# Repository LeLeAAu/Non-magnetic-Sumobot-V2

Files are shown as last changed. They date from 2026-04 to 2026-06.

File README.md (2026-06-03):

# English
# Non-magnetic-Sumobot-V2

## I. Overview
An autonomous ESP32-based robot specifically designed for the UTC SumoBot competition. The project focuses on asymmetric mechanical design and multithreaded processing (FreeRTOS) to optimize high-speed tactical reaction performance.

* **Status:** In Development.
* **License:** MIT License.

Render

---

## II. Directory Structure
* `/main`: Main source code and firmware.
* `/debug`: Testing and sensor calibration code.
* `/Documents`: Research documents, opponent meta analysis, and circuit schematics.
* `/Images`: Project diagrams and images.

---

## III. UTC Competition Rules
* **Dimensions:** Maximum 15x15cm, unlimited height.
* **Weight:** Maximum 1.5kg.
* **Arena (Dohyo):** Circular arena with a 100cm diameter and a 5cm white border. The surface is non-metallic, and magnets are prohibited.
* **Operation:** Fully autonomous. A mandatory 3-second delay before movement must be programmed.
* **Match Format:** 3 rounds, 3 minutes per round. Victory is achieved by flipping or pushing the opponent out of the arena. If both robots fall simultaneously, the robot that touches the ground last wins.

---

## IV. Mechanical & Weight Strategy
The total estimated hardware weight is approximately **1256g**. Instead of maximizing ballast to reach the 1.5kg limit, the bot adopts a "Lightweight & Agile" strategy:

1. **High Mobility:** Reduced inertia allows rapid acceleration and fast flanking maneuvers, exploiting the sluggish movement characteristics commonly found in Tanker-type bots.

2. **Opponent Counterplay:** Most opponents tend to expose their sides and rear. Despite the lower weight, the use of self-locking Worm Gear motors prevents the bot from being pushed backward. This is combined with a Teflon-coated wedge that stays close to the arena floor to lift the opponent's center of mass.

---

## V. Hardware Architecture
* **ESP32 Dual-Core (240MHz):** Processing tasks separated using FreeRTOS.
* **ToF Sensor Array (5x VL53L1X):** Provides 360-degree coverage. Independent XSHUT pins are used for sequential I2C address assignment during startup.
* **Infrared Sensors (5x TCRT5000):** Four edge-detection sensors for white border detection, plus one upward-facing underbody sensor to confirm when the opponent has been lifted onto the wedge.
* **IMU (LSM6DS3):** 6-axis accelerometer and gyroscope sensor. Detects impacts (G-force) and activates the Anti-Lift mechanism.
* **Power System:** High-discharge LiPo 3S 1500mAh 45C battery, Mini560PRO compact buck converter dedicated to the microcontroller power supply, and BTS7960 high-power motor drivers.

---

## VI. Software Architecture & FSM
The system operates using a non-blocking multithreaded architecture:

* **Core 0 (TaskSensor):** Continuously scans the I2C bus. Applies a Median filter for distance measurements and an EMA filter to estimate enemy approach velocity ($v_e$).

* **Core 1 (TaskFSM):** Controls the Finite State Machine (FSM) and PWM signal generation. Data shared between both cores is synchronized safely using a Spinlock Mutex.

---

## VII. ESP32 Pinout
* **Edge & Underbody Sensors (TCRT5000):**
    * Underbody Sensor (DETECT) -> Pin 18 (GPIO39).
    * Rear Left -> Pin 19 (GPIO34). Rear Right -> Pin 20 (GPIO35).
    * Front Left -> Pin 21 (GPIO32). Front Right -> Pin 22 (GPIO33).

* **Main I2C Bus:**
    * SCL -> Pin 23 (GPIO25).
    * SDA -> Pin 24 (GPIO26).

* **XSHUT Control (VL53L1X):**
    * Center (GPIO27), Left (GPIO14), Right (GPIO13), Left Side (GPIO16), Right Side (GPIO17).

* **Motor Driver (BTS7960):**
    * Right LPWM (GPIO18), Right RPWM (GPIO19), Left LPWM (GPIO21), Left RPWM (GPIO22).

* **UI Interface & Notes:**
    * Touch Start Button (TTP223) -> Pin 5 (GPIO4).
    * I2C OLED -> SDA (GPIO23), SCL (GPIO5).
    * **IMPORTANT WARNING:** Never connect components to Pin 27 (GPIO12), as it may cause boot failure issues. Avoid using RX0 and TX0 pins.
      
# Vietnamese
# Non-magnetic-Sumobot-V2
## I. Tổng quan
Robot tự hành ESP32 thiết kế riêng cho giải SumoBot trường UTC. Dự án tập trung vào thiết kế cơ khí bất đối xứng và xử lý đa luồng (FreeRTOS) để tối ưu phản xạ chiến thuật tốc độ cao.

* **Trạng thái:** Đang phát triển.
* **Giấy phép:** MIT License.
Render
---

## II. Cấu trúc thư mục
* `/main`: Mã nguồn và Firmware chính.
* `/debug`: Code test và hiệu chuẩn cảm biến.
* `/Documents`: Tài liệu nghiên cứu, phân tích meta đối thủ, sơ đồ mạch.
* `/Images`: Sơ đồ và hình ảnh dự án.

---

## III. Luật thi đấu UTC
* **Kích thước:** Tối đa 15x15cm, không giới hạn chiều cao.
* **Trọng lượng:** Tối đa 1.5kg.
* **Sàn đấu (Dohyo):** Tròn, đường kính 100cm, viền trắng 5cm. Sàn không kim loại, cấm sử dụng nam châm.
* **Vận hành:** Tự động 100%. Bắt buộc lập trình chờ 3 giây trước khi di chuyển.
* **Thể thức:** 3 hiệp, 3 phút/hiệp. Thắng khi đẩy lật/rớt đối thủ. Chạm đất sau sẽ thắng nếu cùng rớt.

---

## IV. Chiến lược Cơ khí & Trọng lượng
Tổng trọng lượng linh kiện kỹ thuật khoảng **1256g**. Thay vì cố nhồi nhét tạ cho đủ mốc 1.5kg, bot áp dụng chiến thuật "Nhẹ & Linh hoạt":
1.  **Linh hoạt cao:** Giảm quán tính để dễ dàng bứt tốc và xoay góc tạt sườn, tận dụng nhược điểm lù đù của các bot hệ Tanker.
2.  **Khắc chế đối thủ:** Đa số đối thủ thường hở sườn ngang và lưng. Dù nhẹ cân, nhưng việc sử dụng động cơ Worm Gear tự khóa cơ khí giúp bot không bị đẩy lùi. Kết hợp với lưỡi ủi bọc Teflon ép sát mặt sàn để hất bổng trọng tâm đối phương.

---

## V. Kiến trúc Phần cứng
* **ESP32 Dual-Core (240MHz):** Tách biệt xử lý bằng FreeRTOS.
* **Mắt thần ToF (5x VL53L1X):** Phủ sóng 360 độ. Sử dụng các chân XSHUT độc lập để gán địa chỉ I2C tuần tự khi khởi động.
* **Hồng ngoại (5x TCRT5000):** 4 cảm biến góc dò vạch trắng, 1 cảm biến gầm hướng lên trên để xác nhận khi đối thủ đã bị nạy lên lưỡi ủi.
* **IMU (LSM6DS3):** Cảm biến gia tốc 6 trục. Phát hiện va chạm (G-force) và kích hoạt cơ chế chống nhấc bổng (Anti-Lift).
* **Năng lượng:** Nguồn xả cao từ Pin LiPo 3S 1500mAh 45C, mạch giảm áp Mini560PRO siêu nhỏ cấp nguồn riêng cho vi điều khiển, và driver công suất BTS7960.

---

## VI. Kiến trúc Phần mềm & FSM
Hệ thống chạy đa luồng không tắc nghẽn (Non-blocking):
* **Core 0 (TaskSensor):** Quét I2C liên tục. Áp dụng bộ lọc Median cho dữ liệu khoảng cách và bộ lọc EMA để tính vận tốc tiếp cận của địch ($v_e$).
* **Core 1 (TaskFSM):** Điều khiển Cỗ máy trạng thái hữu hạn (FSM) và băm xung PWM. Dữ liệu giữa hai Core được khóa an toàn bằng Spinlock Mutex.
---

## VII. Sơ đồ chân ESP32 (Pinout)
* **Cảm biến gầm & mép (TCRT5000):**
    * Mắt gầm (DETECT) -> Chân 18 (GPIO39).
    * Trái sau -> Chân 19 (GPIO34). Phải sau -> Chân 20 (GPIO35).
    * Trái trước -> Chân 21 (GPIO32). Phải trước -> Chân 22 (GPIO33).

* **Bus I2C chính:**
    * SCL -> Chân 23 (GPIO25).
    * SDA -> Chân 24 (GPIO26).

* **Điều khiển XSHUT (VL53L1X):**
    * Giữa (GPIO27), Trái (GPIO14), Phải (GPIO13), Sườn trái (GPIO16), Sườn phải (GPIO17).

* **Cầu H (BTS7960):**
    * LPWM Phải (GPIO18), RPWM Phải (GPIO19), LPWM Trái (GPIO21), RPWM Trái (GPIO22).

* **Giao diện UI & Lưu ý:**
    * Nút cảm ứng khởi động (TTP223) -> Chân 5 (GPIO4).
    * I2C OLED -> SDA (GPIO23), SCL (GPIO5).
    * **CẢNH BÁO QUAN TRỌNG:** Tuyệt đối không cắm linh kiện vào chân 27 (GPIO12) để tránh lỗi Boot, bỏ qua chân RX0, TX0.

Sơ đồ nối dây tổng thể và các đi-ốt bảo vệ mạch đều được cung cấp cụ thể dưới dạng file thiết kế đồ họa trong thư mục /Documents (Fritzing).

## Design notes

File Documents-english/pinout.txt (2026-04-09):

Pin 18 (GPIO39/SVN) → Bottom sensor (DETECT)
Pin 19 (GPIO34) → Rear left sensor (BL)
Pin 20 (GPIO35) → Rear right sensor (BR)
Pin 21 (GPIO32) → Front left sensor (FL)
Pin 22 (GPIO33) → Front right sensor (FR)

Pin 23 (GPIO25) → I2C SCL for 5 VLX + LMS
Pin 24 (GPIO26) → I2C SDA for 5 VLX + LMS
(Keep the two I2C wires close together)

Pin 25 (GPIO27) → XSHUT 0 (Center)
Pin 26 (GPIO14) → XSHUT 1 (Left)
Pin 27 (GPIO12) → IGNORE! DO NOT CONNECT ANYTHING HERE!
Pin 28 (GPIO13) → XSHUT 2 (Right)

Pin 5 (GPIO4) → Push button (TTP223)

Pin 6 (GPIO16/RX2) → XSHUT 3 (Left side)
Pin 7 (GPIO17/TX2) → XSHUT 4 (Right side)
(Keep the remaining two XSHUT wires close together)

Pin 9 (GPIO18) → Right LPWM
Pin 10 (GPIO19) → Right RPWM
Pin 11 (GPIO21) → Left LPWM

Pins 12 & 13 (RX0, TX0) → IGNORE! (Reserved for code upload/USB)

Pin 14 (GPIO22) → Left RPWM
Pin 15 (GPIO23) → SDA of 0.96 OLED
Pin 8 (GPIO5) → SCL of 0.96 OLED

LMS CS pin → Connect to 3.3V  
LMS SA0 pin → Connect to 3.3V

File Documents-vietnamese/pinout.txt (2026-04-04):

    Pin 18 (GPIO39/SVN) -> Mắt gầm (DETECT)
    Pin 19 (GPIO34) -> Mắt Trái sau (BL)
    Pin 20 (GPIO35) -> Mắt Phải sau (BR)
    Pin 21 (GPIO32) -> Mắt Trái trước (FL)
    Pin 22 (GPIO33) -> Mắt Phải trước (FR)

    Pin 23 (GPIO25) -> I2C SCL của 5 VLX + LMS
    Pin 24 (GPIO26) -> I2C SDA của 5 VLX + LMS
    (Gom 2 dây I2C sát nhau)

    Pin 25 (GPIO27) -> XSHUT 0 (Giữa)
    Pin 26 (GPIO14) -> XSHUT 1 (Trái)
    Pin 27 (GPIO12) -> BỎ QUA! KHÔNG CẮM GÌ VÀO ĐÂY!
    Pin 28 (GPIO13) -> XSHUT 2 (Phải)

    Pin 5 (GPIO4) -> Nút bấm (TTP223)

    Pin 6 (GPIO16/RX2) -> XSHUT 3 (Sườn Trái)
    Pin 7 (GPIO17/TX2) -> XSHUT 4 (Sườn Phải)
    (Gom 2 dây XSHUT còn lại vào sát nhau)

    Pin 9 (GPIO18) -> LPWM Phải
    Pin 10 (GPIO19) -> RPWM Phải
    Pin 11 (GPIO21) -> LPWM Trái

    Pin 12 & 13 (RX0, TX0) -> BỎ QUA! (Dành cho nạp code/USB).

    Pin 14 (GPIO22) -> RPWM Trái
    Pin 15 (GPIO23) -> SDA của 0.96 LED
	Pin 8 (GPIO5) -> SCL của 0.95 LED
	
	Chân CS của LMS -> Nối lên 3.3V
	Chân SA0 của LMS -> nối lên 3.3V

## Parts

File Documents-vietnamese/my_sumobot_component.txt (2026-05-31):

-> Lưỡi ủi phải đến mức cạo mặt sàn, phải mài thật sắc, ép sát sàn (dùng băng dính Teflon) để đảm bảo 100% khi cụng đầu, xe mình chui xuống xe nó
-> Rửa lốp bằng cồn hoặc nước lau kính trước mỗi trận đấu để tẩy bụi

5x VL53L1X
	25x15.6mm
	2g each
	nối chung SDA và SCL của tất cả 5 cảm biến vào 2 dây duy nhất -> 2 chân 2IC
	5 chân GPIO điều khiển XSHUT riêng biệt

5x TCRT5000
	10.2 x 5.8 x 7mm
	~7 g each
	
shangyi 1500mAh 45C 3S
	 22mm x 35mm x 73mm
	 150g
	
2x 5840-31zy Worm Gear
	115x54x34mm
	355g each
	
2x BTS7960
	40x50x12mm
	20g each
	dùng dây cắm nối chập R_EN và L_EN lại với nhau, rồi nối thẳng lên nguồn 3.3V (hoặc 5V logic)
	
DOIT ESP32 CH340 30P  (VIN, 2x GND, 3V3, EN, VP, VM, TX0, RX0, RX2, TX2, D2, D4, D5, D18, D19, D21, D22, D23, D12->15, D12, D13, D14, D25, D26, D27, D32->D35)
mini560 PRO - 3.3V and mini560 PRO - 5V
	29x18x5.4mm
	6g
	
Gy-lsm6ds3  
	13x18
	2g
	0x6B

TTP223
	24x24
	
0.96LED

tụ 470uF/25V
	// đường kính x cao
	10x12.5mm
	1.5g
	
tụ 0.1uF
	3.2x1.6
	0.1g
	
tụ 1000uF
	10x20mm
	2g
	
Điện trở
	
Công tắc bập bênh KCD1
	21x15 (mặt ngoài) - 19x13 (lỗ cắt lắp đặt)
	3g
	
Bánh xe robot V2 65m bằng cao su Đường kính: 65mm. Bề rộng: 27mm Khớp lục giác: 12mm

// Nối 2 tụ 0.22uF ở mỗi đầu chân âm dương mỗi động cơ ra vỏ kim loại - vỏ kim loại sẽ đóng vai trò như lồng faraday

Khung PETG ~ 230g
VL53L1X tổng 10g
TCRT5000 tổng 2.5g
shangyi 150g
5840-31zy Worm Gear 710g
BTS7960 tổng 40g
DOIT ESP32 CH340 30P 12g
mini560 PRO tổng 12g
Gy-lsm6ds3 2g
TTP223 xanh lớn cho là 5g
Bánh xe robot V2 65mm cho là 60g
Công tắc bập bênh KCD1 cho là 3g
Các tụ điện điện trở cho là 20g
Dây dợ không rõ.

No-load
	Rated Voltage: 12V
	RPM 260
	Current 0.3A
Rated-load
	RPM 200
	Current 1.6A
	Torque 5kg.cm
	Power 19.2W
Stall
	Torque 25kg.cm
	Current 6.5A
Starting voltage 2V

Input Voltage: 6 ~ 27Vdc.
Driver: Dual BTS7960 H Bridge Configuration.
Peak current: 43-Amp.
PWM capability of up to 25 kHz.
Control Input Level: 3.3~5V.
Control Mode: PWM or level
Working Duty Cycle: 0 ~100%.
Over-voltage Lock Out.
Under-voltage Shut Down.

Bánh xe 65mm

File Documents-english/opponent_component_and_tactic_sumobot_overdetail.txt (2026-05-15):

// IMPORTANT!!!: The following information only applies to opponents at UTC
// Rare does not mean good
// At UTC, even Rare or Epic is already used by only about 5%
I. Overview of opponent designs
    - Most opponents in Sumo Robot matches tend to use relatively traditional designs, focusing more on practical combat effectiveness rather than complex algorithms. Most of their strategies rely on detecting the opponent in front and pushing them directly out of the arena.

    - Basic design usually includes:
        + A low chassis to improve stability
        + A reinforced front section to withstand collisions
        + A forward-biased center of gravity to increase pushing force
        + The rear is usually less protected
        + This creates common weak points on both sides and the rear of the robot.

II. Distance Sensor Systems (Opponent “Vision”)

    1. Ultrasonic Sensor Group
        Common models:
            HC-SR04 (common), 
			SRF05 (common), 
			FRS04 (uncommon), 
			HC-SR05 (mythic), 
			JSN-SR04T (mythic), 
			RCWL1601 (epic),
			AJ-SR04M (mythic),
			US-015 (mythic),
			US-016 (mythic),
			MaxBotix (MB1010, MB1200) (Legendary)...
        Rarity:
            Common -> Legendary (very widespread, seen in about 80% of student robots)

        Characteristics:
            Extremely cheap and easy to obtain.
            Wide cone-shaped detection angle, easy to detect large opponents.
            Easy to use, plug-and-play.

        Critical weaknesses & tactical exploitation:
            Update speed is limited by the speed of sound. If the opponent moves too fast, the measured data may become inaccurate.
            Has a "blind zone" at very close range. When two robots are in close contact, ultrasonic sensors become completely ineffective.
            Affected by reflection angles: If your robot has angled surfaces, the enemy’s sound waves may reflect upward instead of back to the sensor → The opponent may fail to detect you.
            Very susceptible to noise from mechanical vibration or motor interference.

    2. Optical ToF (Time of Flight) Sensor Group
        Common models:
            VL53L0X,
            VL53L0XV2,
            VL53L5X,
            TOF10120,
            TOF0400F...
        Rarity:
            Uncommon → Rare (depending on investment level)

        Characteristics:
            Uses laser beams to measure photon flight time.
            Extremely high measurement accuracy (millimeter precision).
            Fast response time, less affected by environmental noise compared to ultrasonic sensors.

        Critical weaknesses & tactical exploitation:
            I2C communication can easily freeze (an I2C freeze may lock the entire microcontroller).
            Very narrow beam angle. If the opponent rotates too quickly, the ToF beam may miss your robot.
            The laser can be temporarily blinded by extremely strong light sources (risky if the arena uses powerful lighting).
            Expensive.

    3. Infrared Optical Sensor Group
        Common models:
            GP2Y0A02YK0F (Sharp),
            E18-DNK80...
        Rarity:
            Uncommon

        Characteristics:
            Very fast response speed.
            No trigger pulse required like ultrasonic sensors; outputs direct Analog or Digital signals for very fast processing.

        Critical weaknesses & tactical exploitation:
            Analog output is nonlinear (parabolic response curve), requiring good interpolation algorithms.
            High electrical noise if the opponent's power system is poorly filtered.
            Strongly dependent on color and material. Infrared light is heavily absorbed by black surfaces. If your robot is fully coated in matte black, the detection range of these sensors on the opponent’s robot may be significantly reduced (potentially up to 50%).

    4. Industrial-grade Sensor Group
        Common models:
            CDD-40N,
            E3F-20C1
        Rarity:
            Mythic (~0% usage, no one at UTC has been seen using them yet)

        Characteristics:
            Extremely reliable, designed for factory environments.
            Very stable detection, almost immune to common noise sources in student competitions.

        Critical weaknesses & tactical exploitation:
            Very large and heavy → Literally weighs the team down, disrupts the robot’s center of gravity, making it easier to tip or lose balance when turning.
            High current consumption, increasing battery load.
            Overkill for a high-speed competition environment that requires agility.
			
	5. LiDAR Sensor Series
        Common Models:
            TF-Luna
            TF-Mini Plus
            TF02-Pro
            RPLidar A1/A2
            LD19
            YDLidar X4
        Rarity:
            Legendary (Extremely expensive — almost nobody uses them)
        Characteristics:
            Extremely long measurement range
            Ultra-high scanning frequency, capable of generating a real-time 2D map of the opponent
        Critical Weaknesses & Tactical Exploitation:
            Processing 360° LiDAR data requires a powerful microcontroller
            LiDAR beams can become chaotic when reflected by glossy surfaces such as mirrors or stainless steel

    6. Computer Vision Sensor Series — AI Vision Sensors
        Common Models:
            HuskyLens
            Pixy2 CMUcam5
            OpenMV Cam
        Rarity:
            Legendary (Seriously, almost nobody uses them)
        Characteristics:
            Not only detects where the opponent is, but can also distinguish the front from the rear based on color and shape
            Extremely resistant to interference from non-target objects
        Critical Weaknesses & Exploitation:
            Sudden lighting changes
            Difficult to train
			
III. Opponent Detection Sensor Layout (Sensor Layout & Blind Spots)

    1. "Self-Destruct" Layout (0°)
        Rarity:
            Common (often seen in first-year beginner teams joining just for participation)
        Characteristics:
            Only one sensor pointing straight forward (0°).
        Critical weaknesses & tactical exploitation:
            Extremely narrow field of view.
            Counter strategy: Simply sidestep slightly or move behind the opponent, and their robot effectively becomes a useless brick.

    2. Minimal Layout (0°, 180°)
        Rarity:
            Common (a small upgrade from beginner teams)
        Characteristics:
            Can detect both front and rear.
        Critical weaknesses & tactical exploitation:
            Both sides remain completely blind.

    3. Standard / Spearhead Layout (0°, 45°, -45°)
        Rarity:
            Uncommon (standard layout for most students)
        Characteristics:
            Very good front coverage, including diagonal angles, reducing the risk of direct side attacks.
        Critical weaknesses & tactical exploitation:
            Major blind spot exists in the rear hemisphere (from 90° through 180° to -90°).

    4. Standard Plus Layout (0°, 45°, -45°, 180°)
        Rarity:
            Uncommon
        Characteristics:
            Maintains the strong front coverage of Layout 3 while covering the critical rear blind spot.
        Critical weaknesses & tactical exploitation:
            Still vulnerable on the side flanks (90° and -90°).

    5. Four-Direction / Extended Layout (0°, 90°, -90°, 180°)
        Rarity:
            Rare
        Characteristics:
            Covers all four main directions. Theoretically well-rounded.
        Critical weaknesses & tactical exploitation:
            In real matches: Student FSM algorithms are often not sophisticated enough to smoothly process four sensor inputs simultaneously. Priority-based code (if-else) often favors forward attack commands, causing awkward reactions when attacked from multiple directions.
            New blind spots appear at diagonal angles (45°, 135°, -45°, -135°). Attacking between two sensors diagonally may cause detection delays.

    // ADVANCED SENSOR LAYOUTS
    // If you encounter opponents using these, prepare for a very serious match.

    6. Front Half-Moon Layout (0°, ±45°, ±90°)
        Rarity:
            Mythic
        Tactical meaning:
            Absolute defense for the front hemisphere.
            Effectively blocks most side attack attempts.

    7. X-Shape Critical Diagonal Layout (±45°, ±135°)
        Rarity:
            Epic
        Tactical meaning:
            Ignores traditional vertical/horizontal axes.
            Designed for robots with very strong spin or pivot capabilities.
            Very difficult to predict and counter.

    8. Front-Heavy Focus Cluster (0°, ±15°, ±30°)
        Rarity:
            Legendary
        Strategic Meaning:
            Sacrifices side vision to concentrate 100% of the radar firepower toward the front.
            This layout is commonly paired with extremely advanced target-tracking algorithms.
            The opponent wants to turn their robot into a heat-seeking missile.
            Usually applied to sharp, wedge-shaped bot designs.

	9. Front-Heavy-Max Vortex (0°, ±10°, ±20°, ±30°)
			Rarity:
				Legendary
			Strategic Meaning:
				The most extreme variant of the Focus Cluster layout.
				Performs ultra-fine scanning across the entire front area to ensure your robot always stays centered under the enemy's scoop.
				Teams using this layout almost certainly have highly refined FSM and PID implementations to optimize attack angles.
				Avoid direct frontal engagements at all costs.

	10. Comprehensive 7-Sensor Layout (0°, ±45°, ±45° Wide-Angle, ±90°)
			Rarity:
				Legendary
			Characteristics:
				Features 1 center sensor, 2 narrow diagonal tracking sensors, 2 corner-scanning sensors, and 2 side sensors.
			Strategic Meaning:
				Ensures that every possible attack direction is monitored, especially close-range side blind spots.
				The narrow ±45° sensors can also be cross-angled so their beams cover a larger area at close range.

	11. 11-Sensor Layout
			Rarity:
				God-tier
			Characteristics:
				Uses up to 11 sensors distributed around the robot chassis.
				Was employed by a Romanian team in a professional tournament.
			Strategic Meaning:
				Completely eliminates blind spots.
				No matter where you are within the scan range, the robot can instantly detect and react to your presence.			

IV. Edge Detection System (Emergency brake to prevent ring-out)
    1. Edge Sensor Types
        Entry-level group (TCRT5000):
            Rarity:
                Common
            Characteristics:
                Large modules, bulky, easy to install.
            Critical weakness:
                Extremely sensitive to ambient light.
        Mid-range group (ST188, QRD1114, RPR-220, CNY70):
            Rarity:
                Uncommon
            Characteristics:
                More compact
                Slightly better current characteristics and sensitivity than TCRT5000
                Often integrated into custom PCBs mounted directly under the chassis to save space.
        High-end group (Pololu QTR-1A):
            Rarity:
                Epic
            Characteristics:
                Premium components
                Very compact
                Extremely fast response time and strong ambient light noise immunity.
                Designed for high-speed competitions.
				
    2. Edge Sensor Layout
        Single Front Layout (1× Front)
            Rarity:
                Common (the most "naive" layout).
            Tactical meaning:
                Only detects the white boundary line directly at the center front.
            Critical weakness:
                If the robot is reversing or pushed from behind, it may fall off the arena without resistance.
                During diagonal attacks, the wheels may already be outside before the center sensor detects the boundary.
				
        Longitudinal Dual Layout (1× Front + 1× Behind)
            Rarity:
                Uncommon
            Tactical meaning:
                Fixes the main weakness of the Single Front layout.
                Much safer when being pushed backward or when executing programmed retreat maneuvers.
            Critical weakness:
                The sides of the wheels remain blind spots.
                If hit from the side (90-degree impact) and pushed sideways out of the arena, this system becomes ineffective.
				
        Dual Corner Layout (1× Front Left + 1× Front Right)
            Rarity:
                Common (current meta, most popular layout).
            Tactical meaning:
                Placed at the two front corners.
                Very effective when attacking diagonally or cornering.
                When one sensor detects the boundary, the controller can pivot the robot back toward the arena center.
            Critical weakness:
                Rear vulnerability remains. Reversing is still dangerous.
				
        Four-Corner Layout (1× Front Left + 1× Front Right + 1× Rear Left + 1× Rear Right)
            Rarity:
                Epic
            Tactical meaning:
                A theoretical fortress.
                Nearly complete protection regardless of push direction or rotation angle.
            Critical weaknesses & implementation risks:
                Consumes 4 digital (or analog) MCU pins, complicating wiring.
                Requires solid FSM (Finite State Machine) programming.
                If interrupts or delays are poorly handled, simultaneous sensor triggers may cause oscillation (rapid forward/backward jitter) near the edge, creating an opening for the opponent to finish the match.

V. Microcontrollers (Opponent “Brain” / MCU)

    1. Arduino Group
        Common models:
            Arduino Uno R3 (Common)
            Arduino Uno R4 Minima (Rare)
			Arduino Uni R4 WiFi (Rare)			
            Arduino Nano (Uncommon)
			Arduino Mega 2560 (Uncommon)
			Arduino Leonardo / Micro / Pro Micro (Uncommon)
            Arduino Pro Mini (Rare)
            SAMD21 M0 / M0 Mini (Epic)

        Characteristics:
            Extensive documentation, abundant libraries, very beginner-friendly.
            Usually runs simple sequential logic (if-else structures).

        Critical weaknesses & tactical exploitation:
            Processing speed (especially AVR-based boards like Uno R3/Nano at 16MHz) is relatively slow for real-time combat standards.
            If too many sensors are used without proper optimization, the main loop may become congested (implicit delays).
            This creates reaction latency—your robot may already evade while the opponent reacts too late.

    2. ESP Group
        Common models:
            ESP32-WROOM-32 (Uncommon)
            ESP32-S3 (Rare)
            ESP32-WROOM-38P (Uncommon)
            ESP32 CH340 30P (Uncommon)
			ESP32-C3 (Uncommon)
			ESP8266 (Uncommon) 
			
        Characteristics:
            Very high clock speeds (up to 240MHz), multi-core architecture.
            Easily capable of running complex FSM logic or smooth PID tracking algorithms.

        Critical weaknesses & tactical exploitation:
            Overkill if only running simple sequential logic.
            3.3V logic levels are relatively sensitive to electrical noise from high-power motors.

    3. RP2040 Group
        Common models:
            Raspberry Pi Pico (Epic)
            RP2040 Pro Micro (Epic)

        Characteristics:
            Dual-core ARM Cortex-M0+ architecture, high speed (133MHz), very affordable.
            Features powerful PIO (Programmable I/O) for parallel sensor reading without CPU overhead.

        Critical weaknesses & tactical exploitation:
            Library ecosystem for Sumo Bots is not as plug-and-play as Arduino.
            Very few students utilize even 30% of this chip’s capabilities.
            If encountered, it is likely being used like an expensive Arduino Nano.

    4. ARM Architecture / Specialized MCU Group
        Common models:
            STM32G431CBU6 (Legendary)
            STM32F103C8T6 (Epic)
            STM32F411 Black Pill (Epic)
            STC32G12K128 (Legendary)
            CH32V307VCT6 (Legendary)

        Characteristics & tactical advantages:
            The strength of this group, especially STM32, lies in powerful interrupt systems, DMA, and hardware timers.
            Capable of reading many sensors and controlling motors smoothly with near-zero latency.
            However, the learning curve is very steep.
            Anyone bringing an STM32 board into competition likely understands registers, hardware architecture, and fully controls their FSM.
            These are genuinely strong opponents from a logic standpoint.

    5. High-Performance Compute Group
        Common models:
            Teensy 4.0 (God-tier)
            Teensy 4.1 (God-tier)

        Characteristics:
            Extremely high clock speeds (up to 600MHz), comparable to older desktop computers.

        Critical weaknesses:
            Financial and technical overkill for typical Sumo Bot problems.
            If someone brings such an expensive board into a pushing match, they are either very well funded or simply reused it from a previous major project.
			
VI. Drivetrain System (Mobility Chassis)

    1. Standard Configuration (2 Wheels – 2 Motors)
        Rarity:
            Common (most popular configuration).
        Characteristics:
            Each side uses one motor directly driving one wheel (Direct Drive).
            Highly agile with fast acceleration.
            Smooth pivot/spin turning with an almost zero turning radius.

        Critical weaknesses & tactical exploitation:
            Traction (grip) depends entirely on two very small contact patches.
            Basic dynamics problem: The center of gravity (CG) must be properly positioned over the wheel axis. If the front is too heavy and the rear too light (or vice versa), collision leverage may lift the wheels off the ground → complete loss of static friction, causing the wheels to spin freely while being pushed back.
            Easily tipped or destabilized by strong side impacts.

    2. Alternative / Skid-Steer Configuration (4 Wheels – 2 Motors)
        Rarity:
            Uncommon.
        Characteristics:
            Uses two motors with belt or gear transmission to drive all four wheels simultaneously.
            Excellent stability. Weight distributed across four contact points provides strong grip.

        Critical weaknesses & tactical exploitation:
            Extremely high lateral friction during turning. Rotation is heavy, slow, and draws large current from the battery.
            Against this type, avoid direct frontal engagement.

    3. Track System Configuration (Tank Tracks – 2 Motors)
        Rarity:
            Rare (looks impressive but rarely used in serious competition).
        Characteristics:
            Largest ground contact area → static friction near maximum. Once anchored, pushing it is like pushing a rock.

        Critical weaknesses & tactical exploitation:
            Very slow movement due to energy loss in the track and sprocket system.
            Extremely high power consumption, rapid battery drain, and motor overheating risk if jammed.
            Mechanical weak point: Rubber or 3D-printed tracks often have slack. If your robot has a sharp wedge, a diagonal hit to the side or idler assembly may derail or break the track. Once that happens, the “unstoppable tank” becomes an immobile metal block.

VII. Combat Strategy Classification

    1. Simple brute-force approach – Tanker
        Rarity:
            Common (very frequently encountered).
        Characteristics & equipment:
            Uses high-torque motors, sacrificing speed.
            Simple logic: detect → charge.
        Strategy (FSM):
            Scan → Detect → Rush forward → Push continuously.

        Critical weaknesses & tactical exploitation:
            Sluggishness: Very low angular acceleration, slow turning.
            Side vulnerability: Easily countered by Flankers or Speeders through rear or side attacks. Once pushed sideways, the Tanker’s torque advantage becomes useless.

    2. Speed compensation approach – Speeder
        Rarity:
            Common (an evolutionary step from Tankers).
        Characteristics & equipment:
            High RPM motors with moderate torque.
            More refined FSM code with better approach angle calculation.

        Strategy (FSM):
            Scan (wide search) → Align (target lock) → Attack (high-speed charge).

        Critical weaknesses & tactical exploitation:
            Lower stability due to lighter weight for acceleration optimization.
            High inertia: Missing an attack often causes drifting and loss of control.
            Especially when hitting walls or being blocked by a defensive bot, rebound effects may destabilize control logic.

    3. Wedge specialist – Wedge Lord
        Rarity:
            Uncommon (requires precise mechanical fabrication).
        Characteristics & equipment:
            Extremely low center of gravity.
            Main weapon: ultra-thin, precisely angled wedge.

        Strategy:
            Ignores frontal attacks from Tankers.
            During collision, the wedge slides under the opponent → full PWM push lifts opponent wheels off the ground (removing traction) → push out of the arena.

        Critical weaknesses & tactical exploitation:
            Natural enemy: Imperfect arena surfaces. Scratches, uneven joints, or rough surfaces may cause the wedge to catch and immobilize itself.
            Vulnerable to lateral evasion strategies. The wedge is only effective at the front.

    4. Sacrificial tactician – Edge Camper (Matador style)
        Rarity:
            Mythic (requires unconventional physics thinking).
        Characteristics & equipment:
            Extremely precise edge sensors.
            Specialized drivetrain such as worm gear (self-locking) or motors with strong braking capability.

        Strategy:
            Immediately retreat to the Dohyo edge, stopping about 1 mm from the boundary and locking position.
            Bait the Tanker into charging.
            At impact → drive one wheel forward and one backward → use the opponent’s momentum plus rotational torque to create a throw effect.
            The charging Tanker is flung outward by centrifugal force while the Edge Camper survives by rotating near the edge.

    5. “Steel Wall” system – The Anvil
        Rarity:
            Rare (defensive counter-attack style).
        Characteristics & equipment:
            Motors with very strong braking capability.
            Tires made from high-grip silicone or soft rubber.

        Strategy:
            Moves slowly with a low stance.
            When sensors detect an incoming charge → instantly lock both wheels.
            The opponent collides with an immovable object and absorbs the reaction force → rebounds and loses traction.
            At the rebound moment → full-power counter-attack.

    6. Side attacker – Flanker
        Rarity:
            Epic (requires advanced algorithms).
        Characteristics & equipment:
            Moderate linear speed but extremely high angular velocity (yaw rate).
            Uses focused, X-shape, or side-array sensor layouts.

        Strategy:
            FSM avoids all head-on (0-degree) collisions.
            Upon detecting a frontal opponent → lock one wheel and reverse the other to evade → follow a curved path to strike the opponent’s side blind spot.

    7. Trap setter – Baiter
        Rarity:
            Legendary (requires mastery of both mechanics and pursuit algorithms).
        Characteristics & equipment:
            Extremely strong reverse acceleration.
            Uses kinematic calculations to estimate opponent velocity and acceleration in real time (via sensor arrays or ToF).

        Strategy:
            Intentionally exposes sides or rear to bait attacks.
            Detects the moment the opponent commits to maximum acceleration (PWM saturation) → sudden high-speed retreat or lateral sidestep.
            Result: The opponent crashes into empty space and carries its own inertia out of the arena while the Baiter remains safe.
			
	8. The Ghost — The Stealth Predator
        Rarity:
            Exotic
        Features & Equipment:
            Bot chassis made from sound-absorbing materials and/or coated entirely in matte black paint
            Faceted polygonal design (similar to the F-117 stealth aircraft) to deflect ultrasonic/laser waves away from the opponent's sensors
        Tactics:
            Exploits the opponent’s sensors returning a “nothing detected” state to launch attacks

    // Many opponents choose to combine multiple strategies together.
			
VIII. Motors (Muscles / Propulsion force of the opponent)

    1. Medium Torque Class (Standard mid-tier)
        Common model:
            32GP-31ZY (12V)
        Rarity:
            Common
        Combat specifications:
            No-load speed: 160 RPM | Current: 0.45A
            Rated load: 130 RPM | Torque: 7 kg·cm | Current: 1.8A
            Stall condition: Peak torque 23 kg·cm | Current up to 5A per motor.

        Tactical meaning & exploitation:
            A balanced combination of speed (130 RPM) and pushing power. Suitable for both Tanker and Speeder builds.
            Critical weakness:
                Stall current reaches 5A.
                With a dual-motor setup, a deadlock collision may draw 10A from the battery.
                Using low-quality Li-ion cells or an L298N driver may cause immediate power collapse or driver failure.

    2. Worm Gear Motor Class
        Common model:
            JGY-370 series (24V version)
        Rarity:
            Uncommon
        Combat specifications:
            Variant 1 (Speed):
                Rated 100 RPM | Torque 2.6 kg·cm | Stall 10 kg·cm (very low current: 1.6A)
            Variant 2 (Pulling force):
                Rated 80 RPM | Torque 3.5 kg·cm | Stall 13 kg·cm

        Tactical meaning & exploitation:
            Worm gear provides mechanical self-locking.
            Extremely difficult to push backward if traction is maintained.

        Critical weakness:
            Real torque is relatively modest and speed (80–100 RPM) is very slow.

    3. Heavy-duty industrial class
        Common model:
            JGB37-3530 (24V version)
        Rarity:
            Uncommon
        Combat specifications:
            Rated: 85 RPM | Torque: 5.8 kg·cm
            Stall: Massive torque 23.2 kg·cm

        Tactical meaning & exploitation:
            A motor built for brute pushing.
            Slow but extremely persistent pushing force. A true Tanker motor.
            Running at 24V forces the opponent to carry a large 6S battery pack, reducing chassis agility.

    4. Planetary Gear Motor Class
        Common model:
            36GP-3650
        Rarity:
            Epic (indicates serious mechanical investment)
        Combat specifications:
            Variant 1 (Balanced):
                Rated 140 RPM | Torque 7.8 kg·cm | Stall 18 kg·cm
            Variant 2 (Aggressive):
                Rated 90 RPM | Torque 11.1 kg·cm | Stall 25.2 kg·cm

        Characteristics & advantages:
            Planetary gearboxes handle impacts extremely well and rarely suffer gear damage during high-speed collisions.
            Rated torque up to 11.1 kg·cm allows it to forcefully push most opponents out of the arena.

        Critical weakness:
            High torque but relatively low maximum speed.
			You will have to build a gear-driven power transmission system.

    5. High-end class (Overkill tier)
        Common models:
            MAXON RE35
            PG36-550
        Rarity:
            Mythic (~0% usage)

        Tactical meaning:
            MAXON motors are used in aerospace and heavy industrial robotics. A single RE35 may cost as much as a laptop. Anyone bringing one is either very well funded or repurposing research hardware.
            PG36-550:
                A size-550 class motor capable of extremely high current draw (stall current may reach tens of amps).
                If used without proper thermal design, the opponent’s system may fail before making contact.
				
	6. High-Power DC Motor Series
        Common Model:
            RS-775 (12–24V)
        Rarity:
            Epic
        Tactical Significance:
            Devastating power
        Weakness:
            You will have to build a gear-driven power transmission system.

IX. Common motor drivers

    1. Classic group

        L298N (Uncommon):
            Cheap and extremely common.
            Easy to use and widely available.
            Very low efficiency (old BJT technology).
            Large voltage drop (2V–3V), reducing motor power and generating significant heat (requires large heatsink).
            Max current: 2A per channel.

        L293D (Rare):
            Often integrated into Arduino shields.
            Extremely low current capability (0.6A continuous).
            Too weak for Sumo Bots, likely to fail immediately in collisions.
            Avoid accidental purchase.

    2. Small MOSFET driver group

        TB6612FNG (Uncommon):
            A strong replacement for L298N.
            MOSFET technology: high efficiency, minimal voltage drop, no large heatsink required.
            Very compact.
            Max current: 1.2A continuous (3.2A peak). Suitable for 370 or N20 motors.

        DRV8871 (Uncommon):
            Compact with good efficiency.
            Built-in overcurrent protection.
            Max current: 3.6A peak.

        MX1508 (Rare):
            Extremely cheap and small.
            Used mostly in compact student designs.
            Max current: 1.5A.
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

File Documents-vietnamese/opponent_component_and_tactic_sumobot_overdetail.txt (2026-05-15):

// IMPORTANT!!!: Thông tin sau chỉ áp dụng cho đối thủ ở trường UTC
// Hiếm không đồng nghĩa với tốt
// Ở UTC thì ngay cả Rare hoặc Epic đã là gần như chỉ 5% dùng thôi
I. Tổng quan về thiết kế đối thủ 
	- Đa số đối thủ trong các trận Sumo Robot thường sử dụng thiết kế tương đối truyền thống, tập trung vào hiệu quả thực chiến hơn là thuật toán phức tạp. Phần lớn chiến thuật của họ dựa vào phát hiện đối thủ phía trước và đẩy trực diện ra khỏi sân.

	- Thiết kế cơ bản thường gồm:
		+ Khung robot thấp để tăng ổn định
		+ Phần trước được gia cố để chịu va chạm
		+ Trọng tâm dồn về phía trước để tăng lực đẩy
		+ Phần sau thường ít được bảo vệ hơn
		+ Điều này tạo ra các điểm yếu phổ biến ở hai bên và phía sau robot.

II. Hệ thống Cảm biến khoảng cách (Tầm nhìn của đối thủ)

    1. Nhóm Cảm Biến Siêu Âm - Ultrasonic
        Các mã phổ biến: 
			HC-SR04 (common), 
			SRF05 (common), 
			FRS04 (uncommon), 
			HC-SR05 (mythic), 
			JSN-SR04T (mythic), 
			RCWL1601 (epic),
			AJ-SR04M (mythic),
			US-015 (mythic),
			US-016 (mythic),
			MaxBotix (MB1010, MB1200) (Legendary)...
        Độ hiếm: 
			Common -> Legendary (Tràn lan, gặp ở 80% bot sinh viên)
        Đặc điểm:
            Giá cực rẻ, nhắm mắt cũng mua được.
            Góc quét hình nón khá rộng, dễ dò trúng đối thủ to xác.
            Dễ dùng, cắm là chạy.
        Điểm yếu chí mạng & Khai thác chiến thuật:
            Tốc độ cập nhật bị giới hạn bởi vận tốc âm thanh. Nếu xe đối thủ lao quá nhanh, dữ liệu đo được sẽ bị sai lệch.
            Có "Blind zone" (vùng mù) ở khoảng cách sát ván. Khi hai xe đã áp sát cắn nhau, siêu âm bị mù hoàn toàn.
            Bị ảnh hưởng bởi góc phản xạ: Nếu xe của bạn có thiết kế vát nghiêng, sóng âm của địch sẽ bị dội lên trời thay vì dội về cảm biến -> Đối thủ sẽ không nhìn thấy bạn.
            Rất dễ bị nhiễu do rung động cơ khí hoặc tiếng ồn tạp âm từ motor.

    2. Nhóm Cảm Biến Quang Học ToF (Time of Flight)
        Các mã phổ biến: 
			VL53L0X, 
			VL53L0XV2, 
			VL53L5X, 
			TOF10120, 
			TOF0400F...
        Độ hiếm: 
			Uncommon -> Rare (Tùy mức độ chịu chơi)
        Đặc điểm:
            Sử dụng tia Laser đo thời gian bay của hạt photon.
            Độ chính xác đo lường cực cao (chuẩn milimet).
            Tốc độ phản hồi nhanh, ít bị nhiễu bởi âm thanh môi trường như dòng Ultrasonic.
        Điểm yếu chí mạng & Khai thác chiến thuật:
            Giao tiếp I2C rất dễ bị "treo" (treo I2C là treo luôn vi điều khiển).
            Góc quét dạng tia (Beam) rất hẹp. Nếu bot địch xoay xe quá nhanh, tia ToF có thể quét trượt qua khoảng trống của xe bạn.
            Tia laser dễ bị "mù" tạm thời nếu bị nhiễu bởi nguồn ánh sáng cực mạnh chiếu thẳng vào (rất rủi ro nếu sân đấu có đèn cao áp).
            Chi phí đắt đỏ.

    3. Nhóm Cảm Biến Hồng Ngoại Quang Điện
        Các mã phổ biến: 
			GP2Y0A02YK0F (Sharp), 
			E18-DNK80...
        Độ hiếm: Uncommon 
        Đặc điểm:
            Tốc độ phản hồi nhanh như chớp.
            Không cần băm xung trigger như siêu âm, đẩy thẳng tín hiệu Analog hoặc Digital về chân vi điều khiển xử lý cực lẹ.
        Điểm yếu chí mạng & Khai thác chiến thuật:
            Tín hiệu Analog trả về không tuyến tính (đồ thị cong parabol), yêu cầu đối thủ phải nội suy code tốt.
            Nhiễu điện (Noise) trả về rất cao nếu mạch nguồn (Power system) của đối thủ thiết kế lọc không sạch.
            Phụ thuộc vào màu sắc và vật liệu. Tia hồng ngoại bị hấp thụ mạnh bởi màu đen. Nếu xe bạn sơn đen nhám toàn thân, tầm nhìn của các cảm biến này trên xe địch sẽ bị suy giảm thê thảm (có thể giảm tới 50% khoảng cách phát hiện).

    4. Nhóm Cảm Biến Tiêu Chuẩn Công Nghiệp
        Các mã phổ biến: 
			CDD-40N, 
			E3F-20C1
        Độ hiếm: Mythic (~0% sử dụng, trường UTC chưa thấy pháp sư nào mang vào)
        Đặc điểm:
            Độ tin cậy tuyệt đối, sinh ra để chạy trong nhà máy.
            Phát hiện cực kỳ ổn định, gần như miễn nhiễm với các loại nhiễu thông thường ở sân chơi sinh viên.
        Điểm yếu chí mạng & Khai thác chiến thuật:
            Kích thước khổng lồ và cực kỳ nặng -> Tạ team theo nghĩa đen, phá hỏng trọng tâm (Center of Gravity) của bot, khiến bot dễ bị bốc đầu hoặc mất cân bằng khi rẽ.
            Ăn dòng lớn, tiêu hao năng lượng cao gây áp lực lên pin.
            Overkill với một sân chơi tốc độ cao cần sự linh hoạt.
			
	5. Nhóm cảm biến LiDAR
		Các mã phổ biến:
			TF-Luna
			TF-Mini Plus
			TF02-Pro
			RPLidar A1/A2
			LD19
			YDLidar X4
		Độ hiếm: Legendary (Rất đắt, không ai dùng đâu)
		Đặc điểm:
			Khoảng cách đo cực xa
			Tần số quét cực cao, có thể vẽ được bản đồ 2D của đối thủ trong thời gian thực
		Điểm yếu chí mạng & Khai thác chiến thuật
			Đọc LiDAR 360 cần vi điều khiển mạnh
			Tia LiDAR dễ bị phản xạ hỗn loạn với bề mặt bóng loáng như gương hoặc inox
			
	6. Nhóm Cảm biến thị giác máy tính - AI Vision sensor
		Các mã phổ biến:
			HuskyLens
			Pixy2 CMUcam5
			OpenMV Camp
		Độ hiếm: Legendary (Không ai dùng đâu thề)
		Đặc điểm:
			Không chỉ biết đổi thủ ở đâu, mà còn biết đó là đầu hay đuôi dựa trên màu sắc, hình dáng
			Chống nhiễu cực tốt với các vật cản không phải là mục tiêu đã học
		Điểm yếu chí mạng và khai thác:
			Thay đổi ánh sáng đột ngột
			Khó train

III. Bố trí cảm biến phát hiện đối thủ (Sensor Layout & Blind Spots)
	* Cốt lõi: luôn ưu tiên sử dụng số lượng cảm biến lẻ (3, 5, 7,...). 
    1. Layout "Tự Hủy" (0°)
        Độ hiếm: 
			Common (Thường gặp ở các mầm non năm nhất đi thi cho có phong trào)
        Đặc điểm:
            Duy nhất 1 cảm biến chĩa thẳng về phía trước (0°).
        Điểm yếu chí mạng & Khai thác chiến thuật:
            Góc nhìn cực hẹp
            Cách diệt: Chỉ cần xe bạn lách nhẹ sang một bên hoặc vòng ra sau lưng, bot địch sẽ tự nhiên biến thành một cục gạch phế thải.

    2. Layout Tối Giản (0°, 180°)
        Độ hiếm: 
			Common (Nâng cấp nhẹ của đội năm nhất)
        Đặc điểm:
            Có khả năng nhìn trước và sau.
        Điểm yếu chí mạng & Khai thác chiến thuật:
            Hai bên sườn hoàn toàn mù.
			
    3. Layout Phổ Thông / Mũi Giáo (0°, 45°, -45°)
        Độ hiếm: 
			Uncommon (Layout tiêu chuẩn của đa số sinh viên)
        Đặc điểm:
            Quét mặt trước rất tốt, bao phủ được các góc vát chéo, chống bị tạt sườn trực diện.
        Điểm yếu chí mạng & Khai thác chiến thuật:
            Tử huyệt nằm ở nửa bán cầu sau (từ 90° vòng qua 180° đến -90°)

    4. Layout Phổ Thông Plus (0°, 45°, -45°, 180°)
        Độ hiếm: 
			Uncommon
        Đặc điểm:
            Giữ được lợi thế càn quét mặt trước của layout 3, đồng thời vá được lỗ hổng chết người ở chính diện phía sau.
        Điểm yếu chí mạng & Khai thác chiến thuật:
            Vẫn hở sườn ngang (90° và -90°).

    5. Layout Tứ Tượng / Mở Rộng (0°, 90°, -90°, 180°)
        Độ hiếm: Rare
        Đặc điểm:
            Phủ sóng cả 4 hướng cơ bản. Khá toàn diện trên lý thuyết.
        Điểm yếu chí mạng & Khai thác chiến thuật:
            Thực tế thực chiến: Thuật toán (FSM) của sinh viên thường không đủ tinh vi để xử lý mượt mà cả 4 tín hiệu cùng lúc. Sinh viên thường viết code ưu tiên (if-else) lệnh lao tới trước, dẫn đến việc bot phản ứng cực kỳ lóng ngóng nếu bị tấn công từ 2 hướng.
            Tử huyệt mới xuất hiện ở các góc chéo (45°, 135°, -45°, -135°). Nếu lao chéo vào giữa 2 cảm biến, bot địch sẽ bị "lag" nhận diện.

    // CÁC LAYOUT TẦM NHÌN NÂNG CAO
    // Nếu gặp đối thủ xài form này, chuẩn bị tinh thần đánh một trận khô máu.
	
    6. Bán Nguyệt Phía Trước (0°, ±45°, ±90°)
		Độ hiếm:
			Mythic
        Ý nghĩa chiến thuật:
            Phòng thủ tuyệt đối nửa bán cầu trước. 
			Khóa chặt mọi nỗ lực tạt sườn của đối phương.

    7. Chéo Tử Huyệt X-Shape (±45°, ±135°)
		Độ hiếm:
			Epic
        Ý nghĩa chiến thuật:
            Bỏ qua trục dọc/ngang truyền thống. 
			Sinh ra dành cho những con bot có khả năng xoay tại chỗ (Spin/Pivot) cực gắt.
			Cực kỳ khó chịu và khó bị bắt bài.

    8. Tụ Tiêu Front-Heavy (0°, ±15°, ±30°)
		Độ hiếm: 
			Legendary
        Ý nghĩa chiến thuật:
            Từ bỏ tầm nhìn hai bên, dồn 100% hỏa lực radar về phía mũi xe.
            Layout này thường đi kèm thuật toán bám mục tiêu (Tracking) siêu việt. 
			Đối thủ muốn biến xe của họ thành một quả tên lửa tầm nhiệt.
			Thường ứng dụng cho bot thiết kế nhọn.

    9. Lốc Xoáy Front-Heavy-Max (0°, ±10°, ±20°, ±30°)
		Độ hiếm:
			Legendary
        Ý nghĩa chiến thuật:
            Biến thể cực đoan nhất của Tụ Tiêu. 
			Quét siêu nhuyễn mặt trước để đảm bảo vị trí tương đối của xe bạn luôn nằm ở chính giữa gầm xúc của xe địch. 
			Đối thủ chơi layout này chắc chắn code FSM và PID cực kỳ cứng tay để tối ưu hóa góc đâm. 
			Tránh đối đầu trực diện bằng mọi giá.
			
	10. Layout 7 Cảm biến toàn diện (0°, ±45°, ±45° góc rộng, ±90°)
		Độ hiếm: 
			Legendary
		Đặc điểm: 
			Bố trí 1 cảm biến trung tâm, 2 cảm biến góc chéo hẹp để bám đuổi, 2 cảm biến quét góc (corners) và 2 cảm biến ở hai bên sườn (sides).
		Ý nghĩa chiến thuật: 
            Đảm bảo tất cả các khu vực đối thủ có thể tấn công đều được giám sát, đặc biệt là các góc chết sát sườn. Có thể bố trí bắt chéo góc +-45 độ hẹp để tia quét bao phủ vùng diện tích lớn hơn ở cự ly gần.
		
	11. Layout 11 Cảm biến
		Độ hiếm:
			God-tier
		Đặc điểm:
			Sử dụng tới 11 cảm biến bố trí quanh thân xe.
			Được một đội Romania sử dụng ở giải đấu chuyên nghiệp.
		Ý nghĩa chiến thuật:
			Triệt tiêu hoàn toàn mọi điểm mù. Dù bạn đứng ở bất kỳ đâu trong phạm vi quét, robot đều nhận diện được để phản ứng ngay lập tức.
		
IV. Hệ thống Cảm biến biên - Edge Detection (Phanh khẩn cấp chống rớt đài)
    1. Các dòng Cảm Biến Dò Lai
        Nhóm Phổ Thông (TCRT5000):
            Độ hiếm: 
				Common
            Đặc điểm: 
				Module to, cồng kềnh, dễ lắp.
            Điểm yếu chí mạng: 
				Cực kỳ nhạy cảm với ánh sáng môi trường.
        Nhóm Tầm Trung (ST188, QRD1114, RPR-220, CNY70):
            Độ hiếm: 
				Uncommon.
            Đặc điểm: 
				Nhỏ gọn hơn 
				Dòng xả và độ nhạy tốt hơn TCRT5000 một chút
				Thường được sinh viên tự vẽ mạch in (PCB) tích hợp thẳng xuống gầm xe để tiết kiệm diện tích.
        Nhóm Cao Cấp (QTR-1A của Pololu):
            Độ hiếm: 
				Epic.
            Đặc điểm: 
				Hàng tuyển
				Siêu nhỏ
				Tốc độ phản hồi cực nhanh, chống nhiễu ánh sáng tốt. 
				Sinh ra cho các giải đấu tốc độ cao.

    2. Bố trí Cảm Biến Biên (Edge Sensor Layout)

        Layout Đơn Trước (1x Front)
            Độ hiếm: 
				Common (Layout "ngây thơ" nhất).
            Ý nghĩa chiến thuật: 
				Chỉ dò được vạch trắng ngay giữa mũi xe.
            Điểm yếu chí mạng: 
                Nếu xe đang lùi hoặc bị địch móc lốp đẩy từ phía sau, bot sẽ rơi khỏi sân mà không hề có sức kháng cự.
                Nếu đâm chéo góc, bánh xe có thể đã văng ra ngoài trước khi cảm biến ở giữa kịp nhận diện vạch trắng.

        Layout Kép Dọc (1x Front + 1x Behind)
            Độ hiếm: 
				Uncommon.
            Ý nghĩa chiến thuật: 
				Vá lỗi của Layout Đơn Trước 
				An toàn hơn rất nhiều khi bị đối thủ húc đẩy lùi hoặc khi tự code hàm lùi né đòn.
            Điểm yếu chí mạng: 
				Hai bên hông bánh xe vẫn là góc chết. 
				Nếu địch tạt sườn (húc ngang 90 độ), xe bạn bị trượt ngang ra khỏi sân thì hệ thống này cũng hoàn toàn vô dụng.

        Layout Kép Góc (1x Front Left + 1x Front Right)
            Độ hiếm: 
				Common (Meta hiện tại của giải, phổ biến nhất).
            Ý nghĩa chiến thuật: 
                Đặt ở 2 góc mũi xe. 
				Cực kỳ hiệu quả khi bot chủ động tấn công lệch góc hoặc ôm cua. 
                Khi 1 trong 2 cảm biến chạm vạch, vi điều khiển có thể điều khiển xe quay đầu (Pivot) ngược lại để thoát hiểm vào trong tâm sân.
            Điểm yếu chí mạng: 
				Vẫn là tử huyệt phía sau. Đang lùi là tèo.

        Layout Tứ Trụ Bốn Góc (1x Front Left + 1x Front Right + 1x Behind Left + 1x Behind Right)
            Độ hiếm: 
				Epic.
            Ý nghĩa chiến thuật:
                Pháo đài bất tử (Về mặt lý thuyết). 
				Gần như an toàn tuyệt đối bất kể bị đẩy từ hướng nào hay xoay xe ở góc độ nào.
            Điểm yếu chí mạng & Rủi ro thi công:
                Tốn tận 4 chân Digital (hoặc Analog) của vi điều khiển, làm rắc rối sơ đồ đi dây.
                Yêu cầu khả năng lập trình FSM (Finite State Machine) tốt. Nếu code không xử lý khéo các hàm ngắt (Interrupt) hoặc Delay, khi 2 cảm biến cùng báo tín hiệu, xe sẽ bị "tăng động" (liên tục tiến lùi giật cục) ngay tại mép sân, tạo cơ hội vàng cho đối thủ lao tới dứt điểm.
		
V. Vi điều khiển (Bộ não / MCU của đối thủ)

    1. Nhóm Arduino
        Các mã phổ biến: 
			Arduino Uno R3 (Common)
			Arduino Uno R4 Minima (Rare)
			Arduino Uni R4 WiFi (Rare)
			Arduino Nano (Uncommon)
			Arduino Mega 2560 (Uncommon)
			Arduino Leonardo / Micro / Pro Micro (Uncommon)
			Arduino Pro Mini (Rare)
			SAMD21 M0 / M0 Mini	(Epic)

        Đặc điểm:
            Tài liệu ngập tràn, thư viện sẵn có, cực kỳ dễ lập trình cho người mới.
            Thường chạy các dòng code cơ bản (if-else tuần tự).
        Điểm yếu chí mạng & Khai thác chiến thuật:
            Tốc độ xử lý (đặc biệt là dòng dùng chip AVR cũ như Uno R3/Nano với xung nhịp 16MHz) khá chậm so với tiêu chuẩn chiến đấu thời gian thực.
            Nếu bot địch nhồi nhét quá nhiều cảm biến mà code không tối ưu, vòng lặp (loop) sẽ bị nghẽn (delay). Điều này dẫn đến độ trễ phản xạ - xe bạn lách qua rồi nhưng nửa giây sau bot địch mới nhận ra và quay xe hụt.

    2. Nhóm ESP
        Các mã phổ biến: 
			ESP32-WROOM-32 (Uncommon)
			ESP32-S3 (Rare)
			ESP32-WROOM-38P (Uncommon)
			ESP32 CH340 30P	(Uncommon)
			ESP32-C3 (Uncommon)
			ESP8266 (Uncommon)
        Đặc điểm:
            Xung nhịp cực khủng (lên tới 240MHz), kiến trúc đa nhân (Multi-core).
            Hoàn toàn dư sức chạy các cỗ máy trạng thái (FSM - Finite State Machine) phức tạp hoặc thuật toán PID bám đuổi mượt mà.
        Điểm yếu chí mạng & Khai thác chiến thuật:
            Quá dư thừa (Overkill) nếu chỉ code kiểu "tuần tự" thông thường.
            Mức logic 3.3V của ESP khá nhạy cảm với nhiễu điện (noise) từ motor lớn. 

    3. Nhóm RP2040 
        Các mã phổ biến: 
			Raspberry Pi Pico (Epic)
			RP2040 Pro Micro (Epic)
        Đặc điểm:
            Kiến trúc ARM Cortex-M0+ lõi kép, tốc độ cao (133MHz), giá thành cực kỳ dễ chịu.
            Có bộ PIO (Programmable I/O) đỉnh cao giúp đọc cảm biến song song mà không vướng CPU.
        Điểm yếu chí mạng & Khai thác chiến thuật:
            Hệ sinh thái thư viện cho Sumo Bot chưa "mì ăn liền" như Arduino.
			Hầu như rất ít sinh viên khai thác được dù chỉ 30% sức mạnh của con chip này.
			Nếu gặp, khả năng cao là đối thủ đang dùng nó như một con Arduino Nano đắt tiền.

    4. Nhóm MCU Kiến Trúc ARM
        Các mã phổ biến: 
		STM32G431CBU6 (Legendary)
		STM32F103C8T6 (Epic)
		STM32F411 Black Pill (Epic)
		STC32G12K128 (Legendary)
		CH32V307VCT6 (Legendary)
        Đặc điểm & Lợi thế chiến thuật:
            Sức mạnh của nhóm này, đặc biệt là dòng STM32, nằm ở hệ thống ngắt (Interrupt), DMA và Timer phần cứng cực kỳ mạnh mẽ. Nhóm này có thể đọc hàng tá cảm biến và điều khiển motor mượt mà với độ trễ gần như bằng 0.
            Tuy nhiên, đường cong học tập cực kỳ gắt. 
			Ai dám vác một board STM32 vào sàn đấu thì chắc chắn họ hiểu rất rõ về thanh ghi, kiến trúc phần cứng và làm chủ hoàn toàn được FSM của mình. 
			Đây là đối thủ "cứng cựa" thực sự về mặt logic.

    5. Nhóm Teensy
        Các mã phổ biến: 
			Teensy 4.0 (God-tier)
			Teensy 4.1 (God-tier)
        Đặc điểm:
            Sở hữu xung nhịp khủng khiếp (lên tới 600MHz), con MCU này mạnh ngang một chiếc máy tính đời cũ.
        Điểm yếu chí mạng:
            Hoàn toàn lãng phí tiền bạc và tài nguyên cho bài toán Sumo Bot thông thường. Nếu có ai đem board mạch cả triệu bạc này vào sân cho xe tông nhau, thì khả năng cao đó là một "tay to" tài phiệt hoặc họ lười tháo mạch từ đồ án tốt nghiệp ra.
		
VI. Hệ thống truyền động (Drivetrain / Khung gầm di chuyển)
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

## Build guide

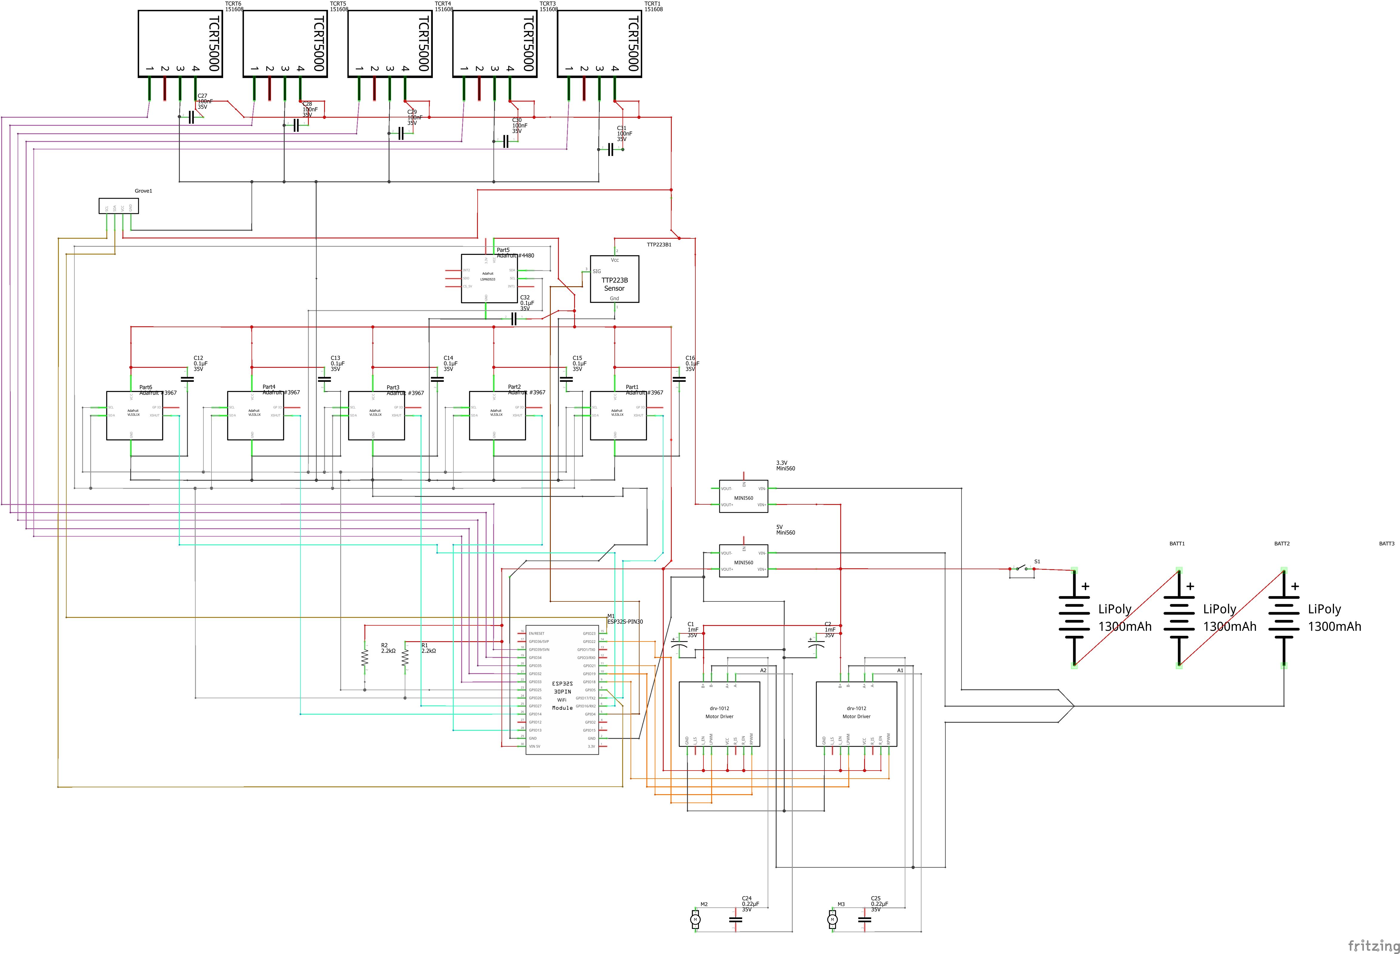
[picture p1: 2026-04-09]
Documents-vietnamese/wiring_schem.png

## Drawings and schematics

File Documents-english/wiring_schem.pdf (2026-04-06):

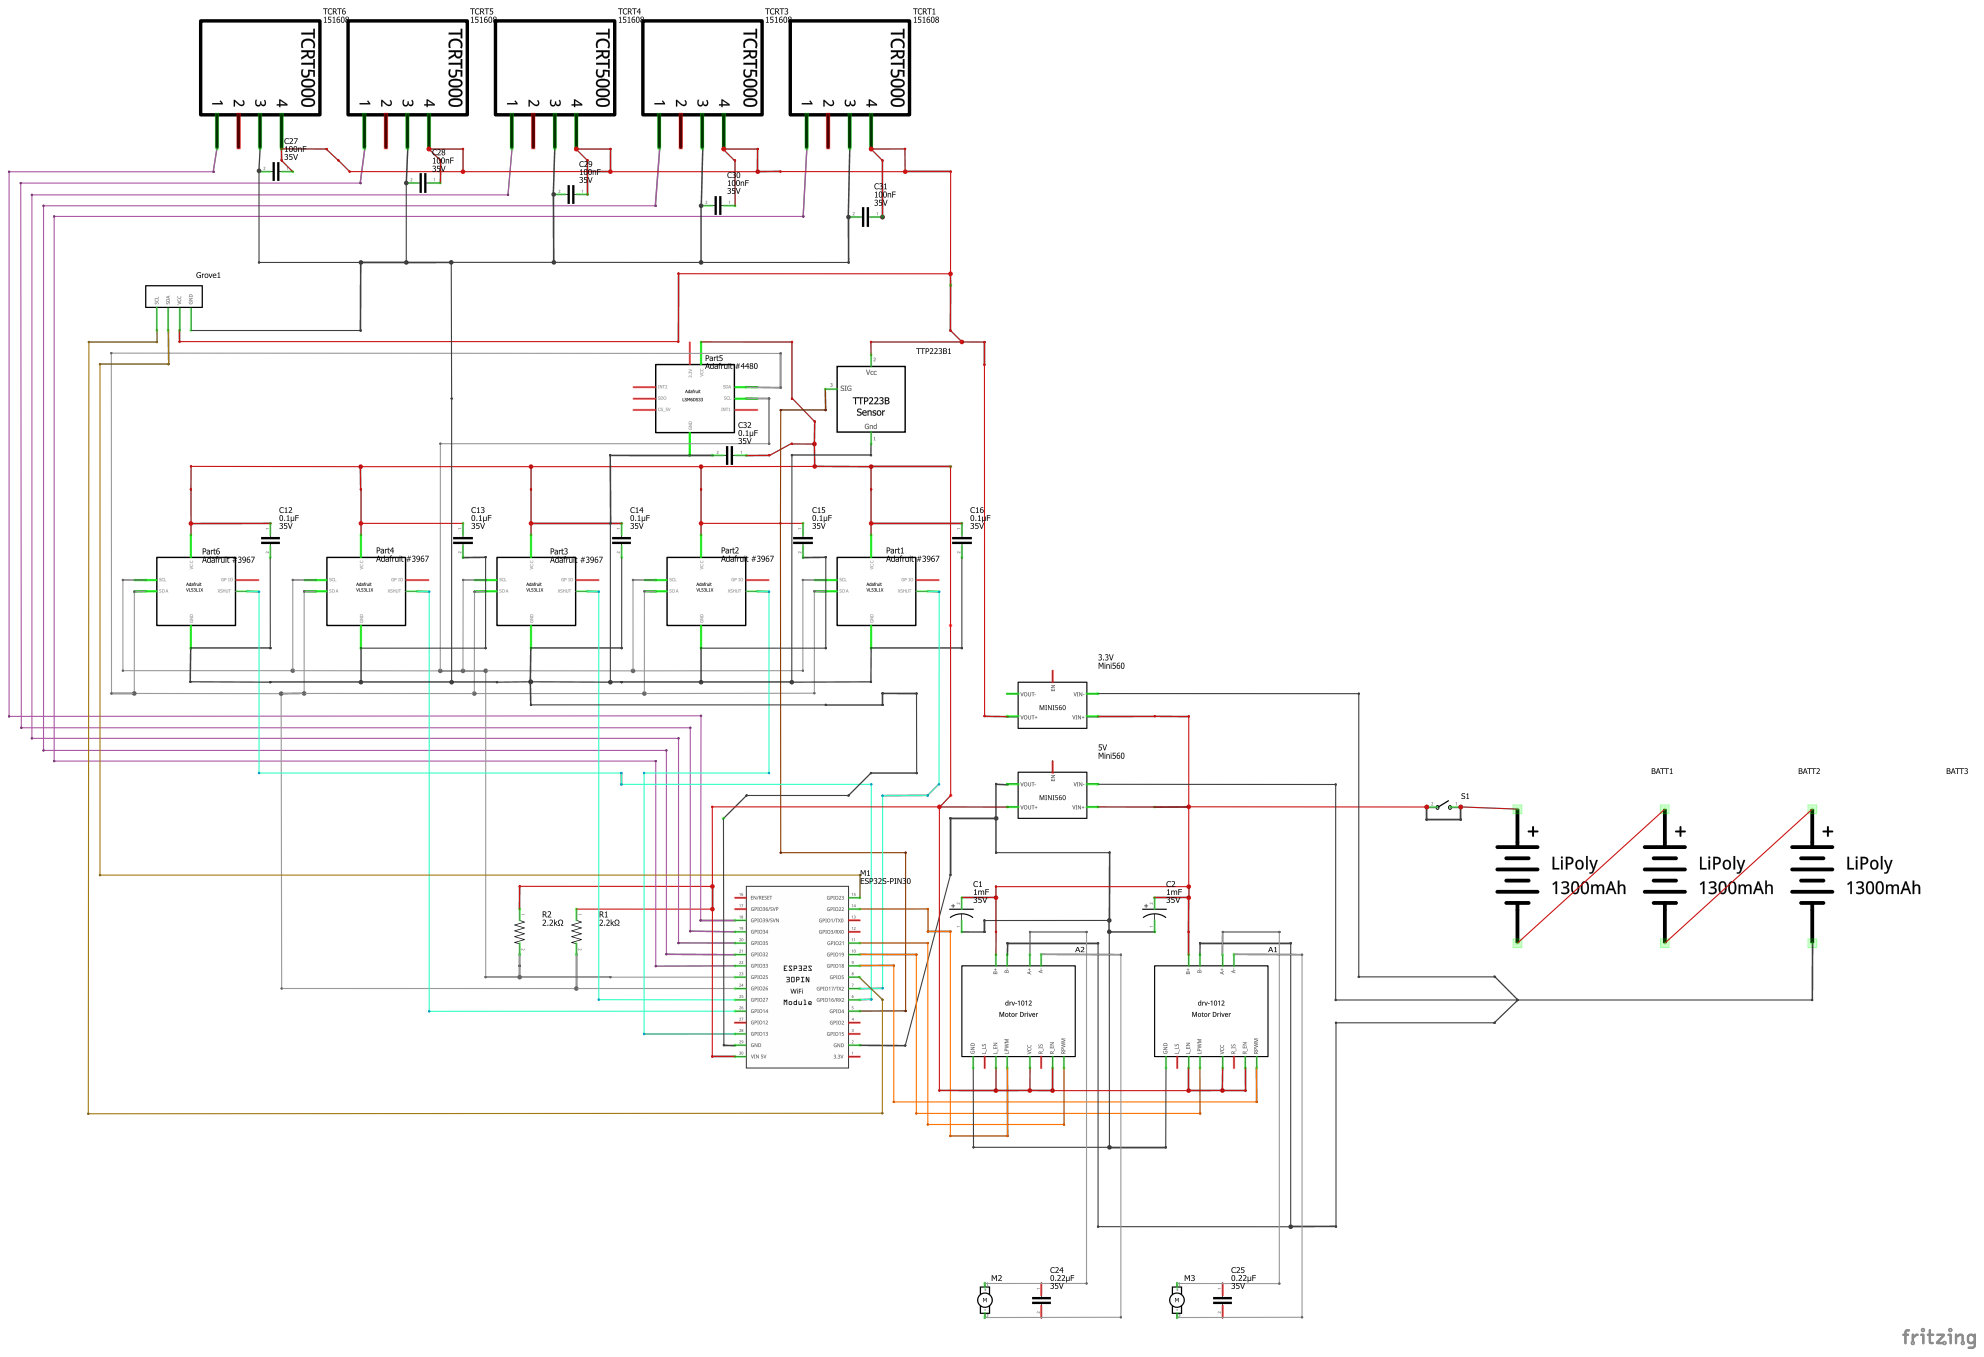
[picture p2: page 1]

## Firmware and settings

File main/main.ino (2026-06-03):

/*
- Core 0: Chạy TaskSensor (Đọc ToF, IMU, TCRT, tính toán Kinematics)
- Core 1: Chạy TaskFSM (Ra quyết định trạng thái) và Loop (Cập nhật OLED/Debug)
- Giao tiếp liên tác vụ thông qua Mutex bảo vệ cấu trúc SystemData
*/

// Việc dùng ToF tạo khoảng delay đo khoảng cách khá lớn. Nếu sau này có một cuộc thi khác thì sẽ chuyển dùng cảm biến ánh sáng khác

// KHÔNG ĐƯỢC GIẢM BUDGET setMeasurementTimingBudget(33000) XUỐNG VÌ SẼ GÂY RA LỖI

// KHÔNG DÙNG CÁC FILTER LỌC NHIỄU GÌ ĐÓ BỞI VÌ ĐO BẰNG VLX CÓ DELAY RẤT LỚN, NẾU DÙNG NÓ CÓ THỂ LÀM GIẢM KHẢ NĂNG PHẢN ỨNG CỦA BOT

// NO ANTI_PUSH. 
// NO FEINT
// CÁC LOGIC PHỨC TẠP chỉ có tác dụng với mấy con Sumobot magnetic bên nhật thôi.

// KHÔNG THÊM CÁC STATE RETREAT. Hãy tập trung vào các logic tấn công


/*
No-load
	Rated Voltage: 12V
	RPM 260
	Current 0.3A
Rated-load
	RPM 200
	Current 1.6A
	Torque 5kg.cm
	Power 19.2W
Stall
	Torque 25kg.cm
	Current 6.5A
Starting voltage 2V

Input Voltage: 6 ~ 27Vdc.
Driver: Dual BTS7960 H Bridge Configuration.
Peak current: 43-Amp.
PWM capability of up to 25 kHz.
Control Input Level: 3.3~5V.
Control Mode: PWM or level
Working Duty Cycle: 0 ~100%.
Over-voltage Lock Out.
Under-voltage Shut Down.

Bánh xe 65mm bề rộng 27mm
*/
// Vấn đề:
/*
- Chuyển sang ATK_LOCK khi d0 và (d1 hoặc d3) ở gần.
- Có lẽ nên để riêng các thông số DIST chp FIRST_FLANK
*/


//Todo
/*
- Nâng cấp các trạng thái tấn công, tập trung vào tấn công
- Sau test thực tế nhớ điều chỉnh các thông số trong case STATE_ATK_FIRST_FLANK:

*/


// Qs - Ans
/*
- Có nên giảm vTaskDelay(pdMS_TO_TICKS(50)); xuống k? - Không
- Nhớ thêm thời gian mù trong mỗi giai đoạn chuyển tiếp
*/

// CMD: pip install pyserial numpy matplotlib

#include "Config.h"
#include "MotorControl.h"
#include "DisplayFace.h"
#include "SensorTask.h"
#include "FSMTask.h"
#include <atomic>
#include "telemetry_utils.h"
#include <freertos/semphr.h>

#if SIMULATION_MODE
volatile uint16_t sim_in_dist[5] = {2000, 2000, 2000, 2000, 2000};
volatile uint16_t sim_in_line[5] = {4095, 4095, 4095, 4095, 4095};
volatile uint16_t sim_in_ttp223 = 0;
#endif

SemaphoreHandle_t paramMutex;

// Khởi tạo đối tượng hệ thống
TwoWire I2COLED = TwoWire(1);
Adafruit_SSD1306 display(SCREEN_WIDTH, SCREEN_HEIGHT, &I2COLED, OLED_RESET);

// Quản lí dữ liệu và trạng thái toàn cục
SystemData sysBuffer[2];               // Double-Buffer // thay thế cho sysData đơn
std::atomic<uint8_t> read_index(0);    // Con trỏ nguyên tử chỉ vị trí buffer FSM sẽ đọc
std::atomic<uint8_t> active_pwm(0);       // Tách riêng PWM ra biến atomic để tránh ghi đè chéo
volatile RobotState currentState = STATE_IDLE;
volatile RobotState previousState = STATE_IDLE;
volatile bool needsDisplayUpdate = false;

// Biến điều khiển nguồn logic
bool go_lock = false;   // Cờ hiển thị chữ GO! sau đếm ngược
uint32_t go_start_time = 0; 
uint32_t state_start_time = 0; // Lưu mốc thời gian bắt đầu của mỗi trạng thái FSM
bool state_just_entered = false;

// Quản lí TASKS
TaskHandle_t TaskSensorHandle = NULL;
TaskHandle_t TaskFSMHandle = NULL;

// Config cảm biến
VL53L1X sensorsToF[5]; 
LSM6DS3 myIMU(I2C_MODE, 0x6B); 

void setup() {
    Serial.begin(115200);
    paramMutex = xSemaphoreCreateMutex();
    // Khởi tạo OLED sớm để hiện thị Boot
    I2COLED.begin(OLED_SDA, OLED_SCL, 100000); // Khởi tạo I2C1
    if (!display.begin(SSD1306_SWITCHCAPVCC, SCREEN_ADDRESS)) {
        DEBUG_PRINTLN(F("OLED fail"));
    } else {
        showLoading(); // Animation khởi động
        display.clearDisplay();
        display.display();
    }

    // Cấu hình bus cảm biến chính
    Wire.begin(I2C_SDA, I2C_SCL); // <--- ÉP I2C CHẠY TRÊN CHÂN 26 VÀ 25
    Wire.setTimeOut(10); // Ép phần cứng I2C tự nhả luồng sau 10ms nếu bị treo
    Wire.setClock(400000); // Fast mode I2C

    bool hardwareError = false;

    // Cấu hình I/0 cho cảm biến TCRT (Dò line và bụng)
    pinMode(PIN_TCRT_FL, INPUT);
    pinMode(PIN_TCRT_FR, INPUT);
    pinMode(PIN_TCRT_BL, INPUT);
    pinMode(PIN_TCRT_BR, INPUT);
    pinMode(PIN_TCRT_DETECT, INPUT);
    // Cấu hình I/0 cho cảm biến chạm TTP223
    pinMode(PIN_TTP223, INPUT_PULLDOWN);

    // Thiết lập PWM cho Motor
    ledcAttach(PIN_MOTOR_L_RPWM, 20000, 8);
    ledcAttach(PIN_MOTOR_L_LPWM, 20000, 8);
    ledcAttach(PIN_MOTOR_R_RPWM, 20000, 8);
    ledcAttach(PIN_MOTOR_R_LPWM, 20000, 8);
#if !SIMULATION_MODE
    // Khởi tạo IMU
    if (myIMU.begin() != 0) {
        DEBUG_PRINTLN("IMU Error!");
        hardwareError = true;
    }

    // Gán địa chỉ động (Sequential XSHUT) cho 5 ToF
    for (int i = 0; i < 5; i++) {
        pinMode(XSHUT_PINS[i], OUTPUT);
        digitalWrite(XSHUT_PINS[i], LOW);
    }
    delay(10);

    for (int i = 0; i < 5; i++) {
        digitalWrite(XSHUT_PINS[i], HIGH);
        delay(10);
        sensorsToF[i].setTimeout(50);
        if (!sensorsToF[i].init()) {
            Serial.print("Lỗi khởi tạo VL53L1X số "); DEBUG_PRINTLN(i);
            hardwareError = true;
        } else {
            sensorsToF[i].setAddress(VLX_ADDRESSES[i]); 
            sensorsToF[i].setDistanceMode(VL53L1X::Medium); // Chế độ đo trung bình 2.9m, tốt hơn chế độ Long và Short dưới ánh sáng mạnh
            sensorsToF[i].setMeasurementTimingBudget(33000); // 33ms/mẫu
            sensorsToF[i].startContinuous(34); // Min là 33, để 34 để tối ưu hoá
        }
    }

    // Nếu lỗi phần cứng nghiêm trọng, dừng hệ thống và báo X_X
    if (hardwareError) {
        display.clearDisplay();
        display.setTextSize(4);
        display.setTextColor(SSD1306_WHITE);
        display.setCursor(28, 0);
        display.print("X_X");
        display.display();
        
        DEBUG_PRINTLN(">>> HARDWARE HALT: SENSOR FAILED! BOOT ABORTED. <<<");
        // Khóa cứng hệ thống ở đây, nháy LED hoặc chờ kỹ sư can thiệp
        while(true) {
            delay(100);
        }
    }
#else
    DEBUG_PRINTLN(">>> SIMULATION MODE: Bypassing hardware init");
#endif
    DEBUG_PRINTLN("Init phan cung xong!");

    // Kích hoạt đa nhiệm, đẩy các Task vào các Core tương ứng
    xTaskCreatePinnedToCore(TaskSensorCode, "TaskSensor", 10000, NULL, 1, &TaskSensorHandle, 0);
    xTaskCreatePinnedToCore(TaskFSMCode, "TaskFSM", 10000, NULL, 3, &TaskFSMHandle, 1);
#if DEBUG_LEVEL >= 1
    xTaskCreatePinnedToCore(TelemetryRxTask, "TelemetryRx", 4096, NULL, 1, NULL, 1);
#endif
}

void TelemetryRxTask(void *pvParameters) {
    uint8_t rx_buffer[256];
    uint8_t decode_buffer[256];
    size_t rx_idx = 0;
    bool in_packet = false;

    while (1) {
        while (Serial.available()) {
            uint8_t c = Serial.read();
            if (!in_packet && c == 0x00) {
                in_packet = true;
                rx_idx = 0;
            } else if (in_packet && c == 0x00) {
                // Kết thúc gói
                if (rx_idx > 0) {
                    int dec_len = cobs_decode(rx_buffer, rx_idx, decode_buffer);
                    if (dec_len >= 3) { // type + length + crc
                        uint8_t type = decode_buffer[0];
                        uint16_t len = decode_buffer[1] | (decode_buffer[2] << 8);
                        if (dec_len >= 3 + len + 2) {
                            uint16_t recv_crc = decode_buffer[3+len] | (decode_buffer[3+len+1] << 8);
                            uint16_t calc_crc = crc16_ccitt(decode_buffer, 3+len);
                            if (recv_crc == calc_crc) {
                                if (type == 0x02) { // PARAM_SET
                                    // payload: param_id (2 byte) + value (4 byte float)
                                    if (len >= 6) {
                                        uint16_t param_id = decode_buffer[3] | (decode_buffer[4] << 8);
                                        float value;
                                        memcpy(&value, &decode_buffer[5], 4);
                                        updateParameter(param_id, value);
                                    }
                                } else if (type == 0x03) { // PARAM_GET
                                    sendAllParameters();
                                } else if (type == 0x05) { // SIM_INJECT_DATA
#if SIMULATION_MODE
                                    if (len >= 20) { // 10 biến uint16 = 20 bytes
                                        memcpy((void*)sim_in_dist, &decode_buffer[3], 10);
                                        memcpy((void*)sim_in_line, &decode_buffer[13], 10);
                                        memcpy((void*)&sim_in_ttp223, &decode_buffer[23], 2); // Trích xuất trạng thái TTP223
                                    }
#endif
                                }
                            }
                        }
                    }
                }
                in_packet = false;
            } else if (in_packet && rx_idx < sizeof(rx_buffer)) {
                rx_buffer[rx_idx++] = c;
            }
        }
        vTaskDelay(pdMS_TO_TICKS(2));
    }
}
void updateParameter(uint16_t param_id, float value) {
    if (xSemaphoreTake(paramMutex, pdMS_TO_TICKS(20)) == pdTRUE) {
        switch (param_id) {
            case 1:  WARN_DIST = (uint16_t)value; break;
            case 2:  STRIKE_DIST = (uint16_t)value; break;
            case 3:  PWM_MAX = (uint8_t)value; break;
            case 4:  PWM_STRIKE_HOLD = (uint8_t)value; break;
            case 5:  PWM_HIGH = (uint8_t)value; break;
            case 6:  PWM_MED = (uint8_t)value; break;
            case 7:  PWM_LOW = (uint8_t)value; break;
            case 8:  V_MAX_60 = value; break;
            case 9:  OMEGA_60 = value; break;
            case 10: KP_STEERING = value; break;
            case 12: ATK_LOCK_TIME = (uint32_t)value; break;
            case 13: TCRT_EDGE_TH = (uint16_t)value; break;
            case 14: TOF_OFFSET[0] = (int16_t)value; break;
            case 15: TOF_OFFSET[1] = (int16_t)value; break;
            case 16: TOF_OFFSET[2] = (int16_t)value; break;
            case 17: TOF_OFFSET[3] = (int16_t)value; break;
            case 18: TOF_OFFSET[4] = (int16_t)value; break;
            default: break;
        }
        xSemaphoreGive(paramMutex);
        DEBUG_PRINTF(">>> PARAM ALTERED: ID %d -> %.2f\n", param_id, value);
    }
}
void sendAllParameters() {
    uint8_t payload[11 * 6]; // 11 tham số, mỗi tham số gồm 2 byte ID + 4 byte Float
    int idx = 0;

    // Biểu thức Lambda hỗ trợ đóng gói nhanh dữ liệu
    auto packParam = [&](uint16_t id, float val) {
        payload[idx++] = id & 0xFF;
        payload[idx++] = (id >> 8) & 0xFF;
        memcpy(&payload[idx], &val, 4);
        idx += 4;
    };

    if (xSemaphoreTake(paramMutex, pdMS_TO_TICKS(50)) == pdTRUE) {
        packParam(1,  (float)WARN_DIST);
        packParam(2,  (float)STRIKE_DIST);
        packParam(3,  (float)PWM_MAX);
        packParam(4,  (float)PWM_STRIKE_HOLD);
        packParam(5,  (float)PWM_HIGH);
        packParam(6,  (float)PWM_MED);
        packParam(7,  (float)PWM_LOW);
        packParam(8,  V_MAX_60);
        packParam(9,  OMEGA_60);
        packParam(10, KP_STEERING);
        packParam(12, (float)ATK_LOCK_TIME);
        packParam(13, (float)TCRT_EDGE_TH);
        packParam(14, (float)TOF_OFFSET[0]);
        packParam(15, (float)TOF_OFFSET[1]);
        packParam(16, (float)TOF_OFFSET[2]);
        packParam(17, (float)TOF_OFFSET[3]);
        packParam(18, (float)TOF_OFFSET[4]);
        xSemaphoreGive(paramMutex);
    }

    // Đóng gói Frame theo đúng định dạng Python mong đợi (Type 0x04)
    uint8_t frame[256];
    frame[0] = 0x04; // PARAM_RESP_TYPE
    frame[1] = idx & 0xFF;
    frame[2] = (idx >> 8) & 0xFF;
    memcpy(frame + 3, payload, idx);

    uint16_t crc = crc16_ccitt(frame, 3 + idx);
    frame[3 + idx] = crc & 0xFF;
    frame[3 + idx + 1] = (crc >> 8) & 0xFF;

    uint8_t cobs_buf[256];
    size_t cobs_len = cobs_encode(frame, 3 + idx + 2, cobs_buf);

    // Xuất luồng nhị phân ra cổng Serial
    Serial.write(0x00);
    Serial.write(cobs_buf, cobs_len);
    Serial.write(0x00);
}

#if DEBUG_LEVEL >= 2
void printDebugInfo(const SystemData& snap) {
    DEBUG_PRINTLN("================================================================");
    
    Serial.print("[FSM] STATE: ");
    Serial.print(getStateName(currentState));
    Serial.print(" | TimeInState: ");
    Serial.print(millis() - state_start_time);
    Serial.print(" ms | PWM Output: ");
    DEBUG_PRINTLN(snap.current_PWM);

    Serial.print("[ToF] Dist: ");
    for(int i=0; i<5; i++) { 
        Serial.print(snap.dist[i]); Serial.print(" "); 
    }
    Serial.print(" | Target: ");
    if (snap.isTargetLost) {
        DEBUG_PRINTLN("LOST");
    } else {
        Serial.print(snap.enemy_angle, 1);
        Serial.print(" deg | v_e: ");
        Serial.print(snap.v_e, 1);
        DEBUG_PRINTLN(" mm/s");
    }

    Serial.print("[TCRT] Line: ");
    for(int i=0; i<4; i++) { 
        Serial.print(snap.line[i]); Serial.print(" "); 
    }
    Serial.print("| Bụng: ");
    DEBUG_PRINTLN(analogRead(PIN_TCRT_DETECT));

    Serial.print("[IMU] P: ");
    Serial.print(snap.pitch, 1);
    Serial.print(" | R: ");
    Serial.print(snap.roll, 1);
    Serial.print(" | [FLAGS]: ");

    if(!snap.edgeDetect && !snap.fallOut && !snap.liftedFront && !snap.liftedRear && 
       !snap.beingLifted && !snap.impactDetected && !snap.closingFast && 
       !snap.sideDanger && !snap.flkPossible) {
        Serial.print("ALL CLEAR");
    } else {
        if(snap.edgeDetect) Serial.print("EDGE! ");
        if(snap.fallOut) Serial.print("FALL! ");
        if(snap.liftedFront) Serial.print("LIFT_F! ");
        if(snap.liftedRear) Serial.print("LIFT_R! ");
        if(snap.beingLifted) Serial.print("BEING_LIFTED! ");
        if(snap.impactDetected) Serial.print("IMPACT! ");
        if(snap.closingFast) Serial.print("RUSHING! ");
        if(snap.sideDanger) Serial.print("SIDE_DANGER! ");
        if(snap.flkPossible) Serial.print("FLANK_READY ");
    }
    DEBUG_PRINTLN("\n");
}
#endif

void loop() {
    uint32_t current_time = millis();

    // Quản lí hiển thị trên OLED
    // Cập nhật giao diện dựa trên trạng thái hiện tại của bot
    if (go_lock && (current_time - go_start_time >= 500)) {
        go_lock = false; // Tắt chữ GO! sau 0.5s
        needsDisplayUpdate = true;
    }

    // LOGIC VẼ MÀN HÌNH ĐỘNG (Dành cho trạng thái rảnh rỗi và chờ)
    static int last_shown_sec = -1;
    static uint32_t last_idle_draw = 0;

    //Biến Tracking để lọc nhiễu hiển thị
    static float last_disp_angle = -999.0;
    static int last_disp_dist = -1;
    static bool last_disp_lost = false;
    static bool is_full_redraw_needed = true; // Cờ yêu cầu vẽ lại bộ khung tĩnh

    if (currentState == STATE_IDLE) { // Giao diện chờ
        last_shown_sec = -1;
        uint32_t idle_duration = current_time - state_start_time;

        // Check 100ms một lần, chỉ đẩy dữ liệu qua I2C nếu có sự thay đổi thật sự
        if (current_time - last_idle_draw >= 100) {
            SystemData snap = sysBuffer[read_index.load()];

            // Định nghĩa mức độ thay đổi để trigger redraw - Deadband hiển thị
            // Lệch > 2 độ hoặc > 15mm thì mới cập nhật số, tránh nhiễu li ti làm nháy số
            bool angle_changed = fabsf(snap.enemy_angle - last_disp_angle) >= 2.0; 
            bool dist_changed = abs(snap.dist[0] - last_disp_dist) >= 15;          
            bool status_changed = (snap.isTargetLost != last_disp_lost);

            bool needs_update = is_full_redraw_needed || status_changed || (!snap.isTargetLost && (angle_changed || dist_changed));

            if (needs_update) {
                if (idle_duration < 30000) {  // Dưới 30 giây -> Thức chờ lệnh
                    if (is_full_redraw_needed) {
                        display.clearDisplay(); // Chỉ clear 1 lần duy nhất khi mới vào State
                        display.setTextSize(2);
                        display.setTextColor(SSD1306_WHITE);
                        display.setCursor(0, 0);
                        display.println("READY...");
                        is_full_redraw_needed = false;
                    }

                    // Partial Update: Tẩy riêng khu vực chứa text thông số ở nửa dưới (Y từ 16 đến 32)
                    display.fillRect(0, 16, 128, 16, SSD1306_BLACK);

                    display.setTextSize(1);
                    display.setCursor(0, 16); 
                    if (snap.isTargetLost) {
                        display.println("Target: LOST");
                    } else {
                        display.printf("Target: %.1f deg\n", snap.enemy_angle);
                    }
                    display.printf("Dist: %d mm\n", snap.dist[0]);
                } else {  // Quá 30 giây -> Lim dim ngủ
                    if (is_full_redraw_needed) {
                        display.clearDisplay();
                        display.setTextSize(4);
                        display.setTextColor(SSD1306_WHITE);
                        display.setCursor(28, 0);
                        display.print("u_u");
                        is_full_redraw_needed = false;
                    }

                    // Partial Update: Tẩy riêng khu vực góc trái trên cùng chứa cụm "D:XXX"
                    display.fillRect(0, 0, 40, 10, SSD1306_BLACK);

                    display.setTextSize(1);
                    display.setCursor(0, 0);
                    if(snap.dist[0] < 2000) {
                        display.printf("D:%d", snap.dist[0]);
                    } else {
                        display.print("D:INF");
                    }
                }

                display.display(); // Chốt xả dữ liệu qua I2C

                // Lưu lại trạng thái để so sánh cho chu kỳ tiếp theo
                last_disp_angle = snap.enemy_angle;
                last_disp_dist = snap.dist[0];
                last_disp_lost = snap.isTargetLost;
            }
            last_idle_draw = current_time;
        }
    }
    else if (currentState == STATE_INIT_DELAY) {
        is_full_redraw_needed = true;
        // Vẽ đếm ngược 3 -> 2 -> 1
        uint32_t elapsed = current_time - state_start_time;
        if (elapsed < 3000) {
            int seconds_left = 3 - (elapsed / 1000);
            if (seconds_left != last_shown_sec && seconds_left > 0) {
                display.clearDisplay();
                display.setTextSize(4);
                display.setCursor(55, 0);
                display.print(seconds_left);
                display.display();
                last_shown_sec = seconds_left;
            }
        }
    } 
    
    else if (currentState == STATE_CALIBRATION) {
        if (is_full_redraw_needed) {
            display.clearDisplay();
            display.setTextSize(2);
            display.setTextColor(SSD1306_WHITE);
            display.setCursor(0, 0);
            display.println("CALIB MODE");
            display.setTextSize(1);
            display.setCursor(0, 20);
            display.println("Motors: LOCKED");
            display.display();
            is_full_redraw_needed = false;
        }
    }

    else {
        is_full_redraw_needed = true;
        // Logic vẽ mặt
        last_shown_sec = -1; // Đảm bảo reset cờ đếm ngược

        if (needsDisplayUpdate) {
            if (go_lock) {
                // Vừa đếm xong 321, in chữ GO! 
                // trong 500ms
                display.clearDisplay();
                display.setTextSize(4);
                display.setCursor(30, 0);
                display.print("GO!");
                display.display();
            } else {
                drawCurrentFace(); // In mặt
            }
            needsDisplayUpdate = false;
        }
    }
    // Gửi telemetry 25Hz (chỉ khi DEBUG_LEVEL >=1)
#if DEBUG_LEVEL >= 1
    static uint32_t last_telemetry_time = 0;
    if (current_time - last_telemetry_time >= 40) { // 40ms một lần
        last_telemetry_time = current_time;
        
        // Đọc snapshot an toàn từ Double-Buffer thông qua cơ chế Lock-Free có sẵn của cậu
        SystemData telemetrySnap = sysBuffer[read_index.load()];
        
        // Đẩy dữ liệu ra Serial sang máy tính
        send_telemetry(telemetrySnap, currentState);
    }
#endif
    // Debug serial mỗi 500ms
#if DEBUG_LEVEL >= 2
    static uint32_t last_debug_time = 0;
    if (current_time - last_debug_time >= 500) { 
        last_debug_time = current_time;
        SystemData snap = sysBuffer[read_index.load()];
        printDebugInfo(snap);
    }
#endif

    vTaskDelay(pdMS_TO_TICKS(50));
}

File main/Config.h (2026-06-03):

#pragma once

// Thư viện hỗ trợ
#include <Arduino.h>
#include <Wire.h>
#include <VL53L1X.h>           
#include <SparkFunLSM6DS3.h>   
#include <Adafruit_SSD1306.h>   
#include <atomic> 
#include <freertos/semphr.h>

// DEBUG CONFIGURATION 
// 0: SILENT MODE - Dành cho thi đấu thực tế (Tắt toàn bộ Serial, tối ưu hiệu năng 100%)
// 1: EVENT MODE - Chỉ in các sự kiện quan trọng (Chuyển State, Lỗi phần cứng ngắt hệ thống)
// 2: VERBOSE MODE - In chi tiết tất cả thông số sensor, kinematics mỗi 500ms (Dùng khi test tại xưởng)
#define DEBUG_LEVEL 0

// Chế độ mô phỏng (bỏ qua phần cứng thật, tự sinh dữ liệu)
#define SIMULATION_MODE 0  // 1 = bật, 0 = tắt

#define CALIBRATION_MODE 0  // 1: Bật chế độ đo đạc tĩnh (Khóa động cơ), 0: Chế độ thi đấu

// Cấu hình Macro
#if DEBUG_LEVEL > 0
    #define DEBUG_PRINT(x) Serial.print(x)
    #define DEBUG_PRINTLN(x) Serial.println(x)
    #define DEBUG_PRINTF(...) Serial.printf(__VA_ARGS__)
#else
    #define DEBUG_PRINT(x)
    #define DEBUG_PRINTLN(x)
    #define DEBUG_PRINTF(...)
#endif


// Chân kết nối ESP32
// Giao tiếp I2C cho ToF và IMU
#define I2C_SDA 26
#define I2C_SCL 25
// Giao tiếp I2C riêng cho OLED nhằm tránh nhiễu bus cảm biến
#define OLED_SDA 23
#define OLED_SCL 5


// Chân cảm biến dò line
#define PIN_TCRT_DETECT 39 // Phát hiện đối thủ
#define PIN_TCRT_BL 34 // Back-left
#define PIN_TCRT_BR 35 // Back-right
#define PIN_TCRT_FL 32 // Front-left
#define PIN_TCRT_FR 33 // Front-right

// Chân điều khiển Motor driver
#define PIN_MOTOR_L_RPWM 22
#define PIN_MOTOR_L_LPWM 21
#define PIN_MOTOR_R_RPWM 19
#define PIN_MOTOR_R_LPWM 18

// Chân cảm biến TTP223
#define PIN_TTP223 4

// Cấu hình màn hình 0.96LED 128x32
#define SCREEN_WIDTH 128
#define SCREEN_HEIGHT 32
#define OLED_RESET -1
#define SCREEN_ADDRESS 0x3C

extern TwoWire I2COLED; 
extern Adafruit_SSD1306 display;



// Constants và Thresholds
// --- Khoảng cách (mm) ---
extern volatile uint16_t CONF_ENY;
extern volatile uint16_t WARN_DIST;
extern volatile uint16_t STRIKE_DIST;
extern volatile int16_t TOF_OFFSET[5];

// --- Thời gian (ms) ---
extern const uint32_t MIN_STT_TIME;
extern const uint32_t PUSH_MS;
extern const uint32_t HOLD_PUSH_MS;
extern const uint32_t TIMEOUT_MAX;
extern volatile uint32_t ATK_LOCK_TIME;

// --- Guard / Safety (ms) ---
extern const uint32_t SIDE_DANGER_TIME;
extern const uint32_t FLK_STABLE_TIME;
extern const uint32_t EDGE_TIMEOUT;
extern const uint32_t MAX_RECOVER_TIME;
extern const uint32_t FLK_DEBOUNCE_TIME;

// --- Hệ thống ---
extern const uint8_t RETRY_LIMIT;
extern const uint8_t MAX_LOCK_RETRIES;
extern volatile uint16_t TCRT_EDGE_TH;
extern const uint16_t TCRT_LIFT_TH;

// --- Kinematics Calibration ---
extern volatile float V_MAX_60;
extern volatile float OMEGA_60;
extern const float BOT_HALF_WIDTH;
extern const float R_SIDE_MARGIN;
extern const float R_SIDE;
extern const float PITCH_TH;
extern const float ACC_IMPACT_TH;
extern const float SENSOR_SIN[5];
extern const float SENSOR_COS[5];
extern const float V_EMA_ALPHA;
extern const float V_DEADBAND_MM;

// --- Motor PWM (0-255) ---
extern volatile uint8_t PWM_MAX;
extern volatile uint8_t PWM_STRIKE_HOLD;
extern volatile uint8_t PWM_HIGH;
extern const uint8_t PWM_JIGGLE;
extern volatile uint8_t PWM_MED;
extern volatile uint8_t PWM_LOW;
extern const uint8_t PWM_TURN_MIN;
extern const uint8_t PWM_PIVOT;

// --- Góc & Cự ly Kinematics ---
extern const float ANGLE_TIGHT;
extern const float ANGLE_WIDE;
extern const float ANGLE_LOST;
extern const float ANGLE_FLANK;
extern const float ANGLE_REAR;
extern const float ANGLE_BIN_RES;
extern volatile float KP_STEERING;
extern const float ANGLE_SLOPPY;
extern const uint16_t DIST_CORNER_SCAN_MAX;   // Cự ly d0 tối đa để kích hoạt check hở góc 45 độ
extern const int16_t TOF_SLID_MISMATCH_TH;    // Độ chênh lệch (mm) xác nhận tia d1/d2 bắn trượt sườn

extern const uint16_t DIST_BLIND;
extern const uint16_t DIST_CLOSE;

extern const uint8_t MEDIAN_WINDOW;
extern const uint8_t XSHUT_PINS[5];
extern const uint8_t VLX_ADDRESSES[5];







// Data Structures và FSM Enums
// Cấu trúc dữ liệu và trạng thái

// Định nghĩa các trạng thái FSM
// Sửa lại danh sách enum:
enum RobotState {
    STATE_IDLE, STATE_INIT_DELAY,
    STATE_ATK_FIRST_FLANK,
    STATE_ATK_STRIKE, STATE_ATK_LIFT, 
    STATE_ATK_DELAY_RUSH, STATE_ATK_LOCK, STATE_ATK_STALEMATE_BRAKE,
    STATE_DEF_ANTI_PUSH, STATE_DEF_SIDE_GUARD, STATE_DEF_REAR_GUARD, 
    STATE_DEF_EDGE_AVOID, STATE_DEF_ANTI_LIFT, STATE_DEF_LAST_STAND,
    STATE_REC_RECOVER, STATE_SEARCH_ENEMY,
    STATE_CALIBRATION
};
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

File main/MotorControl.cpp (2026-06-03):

#include "Config.h"
#include "MotorControl.h"
#include <Arduino.h>

void setMotors(int leftSpeed, int rightSpeed) {
    // Ràng buộc giới hạn an toàn
    leftSpeed = constrain(leftSpeed, -PWM_MAX, PWM_MAX);
    rightSpeed = constrain(rightSpeed, -PWM_MAX, PWM_MAX);

    // Các biến static để ghi nhớ trạng thái giữa các vòng lặp
    static int last_left_sign = 0;   // 1: Tiến, -1: Lùi, 0: Dừng
    static int last_right_sign = 0;
    static uint32_t left_deadtime_start = 0;
    static uint32_t right_deadtime_start = 0;
    static bool left_in_deadtime = false;
    static bool right_in_deadtime = false;

    const uint32_t DEADTIME_MS = 12; // 30ms delay theo yêu cầu
    uint32_t current_time = millis();

    // 1. Lấy dấu của lệnh yêu cầu hiện tại
    int req_left_sign = (leftSpeed > 0) ? 1 : ((leftSpeed < 0) ? -1 : 0);
    int req_right_sign = (rightSpeed > 0) ? 1 : ((rightSpeed < 0) ? -1 : 0);

    // 3. THUẬT TOÁN TRACTION CONTROL (VUỐT GA CHỐNG TRƯỢT TIRE SLIP)
    static int current_pwm_L = 0;
    static int current_pwm_R = 0;
    static uint32_t last_ramp_time = 0;
    
    uint32_t dt = current_time - last_ramp_time;
    last_ramp_time = current_time;
    if (dt > 50) dt = 5; // Lọc nhiễu thời gian nếu OS bị suspend
    
    // Tốc độ tăng ga: 3 đơn vị PWM cho mỗi 1ms (Mất ~85ms để đạt max 255). 
    // Thông số này đủ gắt để húc, nhưng đủ mềm để lốp bắt được ma sát tĩnh.
    int max_step = dt * 3; 

    // Hàm Lambda xử lý vuốt ga thông minh
    auto smartRamp = [](int target, int current, int step) -> int {
        // Phanh khẩn cấp hoặc bị FSM ép đảo chiều gắt -> Cắt ga ngay lập tức
        if (target == 0 || (target > 0 && current < 0) || (target < 0 && current > 0)) {
            return target; 
        }
        // Đang lấy đà tiến lên
        if (target > 0 && target > current) return min(target, current + step);
        // Đang lấy đà lùi lại
        if (target < 0 && target < current) return max(target, current - step);
        
        // Đang giảm tốc độ (nhưng chưa về 0) -> Chấp nhận xả ga ngay
        return target; 
    };

    // Áp dụng bộ lọc cho tín hiệu đã qua xử lý Deadtime
    leftSpeed = smartRamp(leftSpeed, current_pwm_L, max_step);
    rightSpeed = smartRamp(rightSpeed, current_pwm_R, max_step);

    // Cập nhật bộ nhớ cho vòng lặp sau
    current_pwm_L = leftSpeed;
    current_pwm_R = rightSpeed;

    // XẢ TÍN HIỆU RA CHÂN VẬT LÝ
    // Lúc này leftSpeed và rightSpeed đã được bộ lọc phía trên xử lý an toàn
    
    // Xả tín hiệu ra Motor Trái
    if (leftSpeed > 0) {
        ledcWrite(PIN_MOTOR_L_RPWM, leftSpeed);
        ledcWrite(PIN_MOTOR_L_LPWM, 0);
    } else if (leftSpeed < 0) {
        ledcWrite(PIN_MOTOR_L_RPWM, 0);
        ledcWrite(PIN_MOTOR_L_LPWM, abs(leftSpeed));
    } else {
        ledcWrite(PIN_MOTOR_L_RPWM, 0);
        ledcWrite(PIN_MOTOR_L_LPWM, 0);
    }

    // Xả tín hiệu ra Motor Phải
    if (rightSpeed > 0) {
        ledcWrite(PIN_MOTOR_R_RPWM, rightSpeed);
        ledcWrite(PIN_MOTOR_R_LPWM, 0);
    } else if (rightSpeed < 0) {
        ledcWrite(PIN_MOTOR_R_RPWM, 0);
        ledcWrite(PIN_MOTOR_R_LPWM, abs(rightSpeed));
    } else {
        ledcWrite(PIN_MOTOR_R_RPWM, 0);
        ledcWrite(PIN_MOTOR_R_LPWM, 0);
    }
}

void driveBot(int leftSpeed, int rightSpeed) {

    // STATIC FRICTION COMPENSATOR
    // Thời gian chích xung PWM cao để thắng sức ỳ ban đầu
    const uint32_t KICKSTART_MS = 15;
    // Ngưỡng PWM để xem xét kích hoạt (nếu tốc độ yêu cầu nằm trong khoảng lờ đờ)
    const int SLOW_TURN_THRESHOLD = 120; 
    // Xung lực mồi (thường để 150-200, mình set mặc định 180 cho mượt)
    const int KICK_PWM = 220;

    uint32_t elapsed_in_state = millis() - state_start_time;

    // Chỉ can thiệp nếu FSM đang ở trong giai đoạn 30ms đầu tiên của 1 State mới
    if (elapsed_in_state < KICKSTART_MS) {
        
        // XỬ LÝ MOTOR TRÁI
        // Nếu lệnh yêu cầu đang bắt chạy chậm, nhưng lại không phải là lệnh phanh cứng (0)
        if (abs(leftSpeed) > 0 && abs(leftSpeed) < SLOW_TURN_THRESHOLD) {
            // Giữ nguyên chiều (dấu), chỉ bơm áp lên KICK_PWM
            leftSpeed = (leftSpeed > 0) ? KICK_PWM : -KICK_PWM;
        }

        // XỬ LÝ MOTOR PHẢI
        if (abs(rightSpeed) > 0 && abs(rightSpeed) < SLOW_TURN_THRESHOLD) {
            rightSpeed = (rightSpeed > 0) ? KICK_PWM : -KICK_PWM;
        }
    }

    // Sau khi lọc xong, đẩy xuống tầng dưới
    setMotors(leftSpeed, rightSpeed);

    int fsm_last_pwm = (leftSpeed + rightSpeed) / 2;

    active_pwm.store(fsm_last_pwm);
}

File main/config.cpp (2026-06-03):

#include "Config.h"
// Constants và Thresholds
// --- Khoảng cách (mm) ---
volatile uint16_t CONF_ENY = 1300;      // min distance xác nhận có đối thủ (tạm gán 1000mm)
volatile uint16_t WARN_DIST = 550;      // ngưỡng cảnh báo đối thủ ở cự ly nguy hiểm
volatile uint16_t STRIKE_DIST = 450;    // khoảng cách bung lực tấn công (dành riêng cho d0)

// --- Thời gian (ms) ---
const uint32_t MIN_STT_TIME = 50;    // thời gian tối thiểu giữ 1 state
const uint32_t PUSH_MS = 500;        // thời gian bơm xung lực đẩy
const uint32_t HOLD_PUSH_MS = 500;   // thời gian duy trì lực đẩy sau xung đầu
const uint32_t TIMEOUT_MAX = 500;    // timeout chờ tối đa
volatile uint32_t ATK_LOCK_TIME = 250;  // thời gian tối đa trong STATE_ATK_LOCK

// --- Guard / Safety (ms) ---
const uint32_t SIDE_DANGER_TIME = 80;   // thời gian tối thiểu d báo < WARN_DIST để chốt sideDanger
const uint32_t FLK_STABLE_TIME = 100;   // thời gian flkPossible phải giữ TRUE liên tục
const uint32_t EDGE_TIMEOUT = 300;      // thời gian phải sạch vạch trắng trước khi thoát RECOVER
const uint32_t MAX_RECOVER_TIME = 800;  // thời gian tối đa cho 1 phase RECOVER
const uint32_t FLK_DEBOUNCE_TIME = 30;  // Thời gian ân hạn (chống dội) khi mất điều kiện tạt sườn

// --- Hệ thống ---
const uint8_t RETRY_LIMIT = 7;          // giới hạn số lần thử đẩy trong 1s để chống rung lắc
const uint8_t MAX_LOCK_RETRIES = 2;     // số lần tối đa ngắm/đẩy hụt trước khi reset state
volatile uint16_t TCRT_EDGE_TH = 500;      // Dưới 500 là vạch trắng
const uint16_t TCRT_LIFT_TH = 3000;     // Dưới 3000 là có bụng địch đè lên (Bình thường chĩa lên trời là ~4095)
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

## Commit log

2026-04-06 Add files via upload
    wiring schem in Fritzing
2026-04-09 Add eng-ver. Documents
    [wiring.fzz]
2026-05-14 fix bug + fix animation bug + debugging
    [Config.h, FSMTask.cpp, MotorControl.cpp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]
2026-05-29 Fix Infinite Blocking Issue
    VN:
    Problems: xSemaphoreTake(dataMutex, portMAX_DELAY) gây block vô thời hạn nếu task kia treo
    Giải quyết:
    Thay thế Mutex bằng Double-Buffering + Atomic Pointer Swap kết hợp Timestamp Watchdog.
    EN:
    Problems:
    xSemaphoreTake(dataMutex, portMAX_DELAY) can cause indefinite blocking if another task hangs or becomes unresponsive.
    Solution:
    Replace the Mutex mechanism with Double Buffering + Atomic Pointer Swap combined with a Timestamp Watchdog.
    [Config.h, FSMTask.cpp, MotorControl.cpp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]
2026-05-29 OLED Code Optimization
    Kết hợp Partial Update và Delta Tracking nhằm giảm việc ngốn băng thông và nguy cơ nghẽn bus cảm biến cho OLED
    EG:
    Implement Partial Update and Delta Tracking techniques to reduce bandwidth consumption and minimize the risk of sensor bus congestion caused by OLED communication.
    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
2026-05-29 Debug configuration + Bug fixed
    Debug configuration + Bug fixed
    [Config.h, FSMTask.cpp, main.ino]
2026-05-29 Fix lacks runtime monitoring
    Thêm checkSensorHealth() mỗi 1s:
    timeout ToF,
    IMU disconnect,
    TCRT stuck.
    Nếu lỗi >3 lần → STATE_DEF_LAST_STAND
    Add checkSensorHealth() every 1 second to detect:
    - ToF timeout
    - IMU disconnection
    - TCRT stuck state
    If a fault occurs more than 3 times → switch to STATE_DEF_LAST_STAND.
    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
    [Config.h, FSMTask.cpp, SensorTask.cpp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]
2026-05-29 atk random -> determinism and versa
    - Cải thiện STATE_ATK_STRIKE và STATE_ATK_LOCK
    - ATK_LOCK_TIME = 500 cố định -> Scale theo dist[0]: lock_time = map(dist[0], 200, 1500, 200, 700)
    - Improve STATE_ATK_STRIKE and STATE_ATK_LOCK behaviors.
    - Replace the fixed ATK_LOCK_TIME = 500 with dynamic scaling based on dist[0]: lock_time = map(dist[0], 200, 1500, 200, 700)
    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
    [Config.h, FSMTask.cpp, config.cpp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]
2026-05-29 improve runtime ToF watchdog and auto-reinit
    Fix Bug and improve runtime ToF watchdog and auto-reinit
    [Config.h, SensorTask.cpp, config.cpp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]
2026-05-29 Add IMU runtime watchdog recovery
    Tự động khởi tạo lại IMU nếu không nhận được cập nhật hợp lệ trong hơn 200 ms.
    Reinitialize IMU if no valid update is received for >200 ms.
    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
2026-05-29 Add STATE_ATK_ANVIL_BREAKER
    - Kích hoạt một đòn tấn công bọc cánh góc rộng khi ATK_LOCK thất bại hai lần liên tiếp đối với mục tiêu đứng yên (v_e < 50 mm/s).
    - Hành động:
    + Nhanh chóng rút lui về phía sau để tách khỏi mục tiêu
    + Thực hiện đòn tấn công vòng cung bán kính lớn từ bên hông, với góc tiếp cận khoảng 45°.
    - Trigger a wide-angle flank attack when ATK_LOCK fails twice against a stationary opponent (v_e < 50 mm/s).
    - Behavior:
    + Quick backward disengage
    + Large-radius side attack at ~45° approach angle
    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
    [Config.h, FSMTask.cpp, main.ino]
2026-05-29 Remove redundant and duplicated code blocks.
    - Xoá các dòng code lặp lại và không cần thiết
    - Remove redundant and duplicated code blocks.
    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
2026-05-30 make some minor change
    - Cải thiện INIT_DELAY
    - Thêm ưu tiên tránh biên cho STATE_ATK_LOCK
    - Fix đơ bot trong khoảng thời gian ngắn trong STATE_ATK_LOCK
    - Thêm tính năng ghi log và playback trong robot_telemetry_ui.py
    - Improved INIT_DELAY
    - Added edge-avoidance priority for STATE_ATK_LOCK
    - Fixed brief bot freezing during STATE_ATK_LOCK
    - Added logging and playback functionality to robot_telemetry_ui.py
    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
    [FSMTask.cpp, robot_telemetry_ui.py]
2026-05-30 Refactored, Simulation mode, minor improvements
    - Gộp các file nhỏ lại thành file lớn hơn
    - Thêm chế độ mô phỏng
    - minor improvements.
    - Merged smaller files into larger, more consolidated modules.
    - Added a simulation mode.
    - Minor improvements.
    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
2026-05-30 telemetry fix
    fix telemetry errors
    [robot_telemetry_ui.py]
2026-05-30 no longer need debug_new
    [Config.h, FSMTask.cpp, MotorControl.cpp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]
2026-05-30 Make some minor change
    - Dùng Gyro để xoay vòng chính xác thay vì Delay mù
    - Thay vì lùi hết ga ở state tránh edge -> xoay nhẹ một chút
    - reset từng ToF một
    - Thêm tính năng đọc cờ trạng thái của VLX
    - Thêm tí chống dao động STATE
    - Thêm CALIBRATION_MODE
    - Use gyro-based turning instead of blind delays.
    - Improve edge avoidance with slight turn correction.
    - Reset ToF sensors individually.
    - Add VLX status flag reading.
    - Reduce state oscillation.
    - Add CALIBRATION_MODE.
    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
    [Config.h, FSMTask.cpp, SensorTask.cpp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]
2026-05-30 fix
    - fix Double Buffering
    [SensorTask.cpp]
2026-05-31 FUCK ANTI_PUSH
    FUCK ANTI_PUSH. LOGIC này chỉ có tác dụng với mấy con Sumobot magnetic bên nhật thôi!
    FUCK ANTI-PUSH. This logic only works with those Sumobot magnetic robots from Japan!
2026-06-03 When Theory Meets Reality
    + Đơn giản hoá FSM lại
    + Thay đổi các thông số
    + Tối ưu các STATE còn lại
    - Simplified the FSM
    - Tuned parameters
    - Optimized remaining states
    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
2026-06-04 feat(tactics): optimize rear edge anchor brake with enemy angle and distance constraints
    - Added enemy_angle check (-10 to +10 deg) to prevent locking when flank/slip.
    - Added dist[0] < STRIKE_DIST constraint to avoid false locks from far away.
    - Synchronized FSM state logic between Global Safety and STATE_ATK_STRIKE.
    [FSMTask.cpp]
